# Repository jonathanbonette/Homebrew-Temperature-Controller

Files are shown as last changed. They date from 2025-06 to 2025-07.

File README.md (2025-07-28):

# 🍺 Controlador de Temperatura para Produção de Cerveja Artesanal

Um sistema embarcado moderno e modular para monitoramento e controle térmico durante a brassagem de cerveja artesanal, baseado em perfis de temperatura ajustáveis e lógica de controle robusta.

## Índice

1. [Visão Geral](#visão-geral)  
2. [Objetivos](#objetivos)  
3. [Tecnologias Utilizadas](#tecnologias-utilizadas)  
4. [Arquitetura do Sistema](#arquitetura-do-sistema)  
5. [Modelagem e Lógica de Estados](#modelagem-e-lógica-de-estados)  
6. [Código e Integração Itemis](#código-e-integração-itemis)
7. [Plano de Entregas e Metodologia](#plano-de-entregas-e-metodologia)  
8. [Requisitos do Projeto](#requisitos-do-projeto)  
9.  [Funcionalidades Extras](#funcionalidades-extras)  
10. [Receitas Utilizadas](#receitas-utilizadas)
11. [Resultados e Logs de Processo](#resultados-e-logs-de-processo)
12. [Considerações Finais e Melhorias Futuras](#considerações-finais-e-melhorias-futuras)
13. [Changelog](#changelog)

---

### Visão Geral

Este projeto tem como objetivo desenvolver um controlador inteligente para automatizar o processo de fabricação de cerveja artesanal. O sistema gerencia a temperatura do mosto e ativa automaticamente um mixer, garantindo homogeneidade térmica e aderência a curvas de temperatura personalizáveis.

Com uma arquitetura flexível, o sistema pode ser simulado em ambiente de desenvolvimento e implantado em microcontroladores reais, permitindo testes eficientes e facilidade de manutenção.

### Objetivos

- **Controle térmico preciso:** Manter o mosto dentro da faixa desejada com controle PID e/ou ON/OFF com histerese.
- **Homogeneização eficiente:** Acionar o mixer automaticamente conforme a diferença de temperatura entre sensores.
- **Curvas customizáveis:** Permitir definição e carregamento de receitas personalizadas.
- **Segurança embutida:** Detectar falhas e fornecer alertas visuais/sonoros.
- **Interface acessível:** Oferecer informações em tempo real via display e comunicação serial.
- **Portabilidade e testes:** Simular em PC e transferir facilmente para o ESP32.

---

### Tecnologias Utilizadas

- **Plataforma:** ESP32 (com suporte a FreeRTOS)
- **Linguagem:** C++ com princípios de orientação a objetos
- **Modelagem de Estados:** itemis CREATE / itemis CREATE
- **Interface com Usuário:**
  - Display OLED ou LCD via I2C
  - Teclado matricial 4x4
  - Comunicação UART com PC
- **Sensores:** Temperatura (I2C ou OneWire)
- **Atuadores:** Resistência (PWM), Mixer (GPIO/PWM)
- **Versionamento:** Git + GitHub
- **Documentação:** Doxygen
- **Testes:** Unity ou Google Test *(em definição)*

---

### Arquitetura do Sistema
O controlador é baseado em uma arquitetura modular e desacoplada, onde o microcontrolador ESP32 atua como o núcleo de processamento central, executando tarefas paralelas por meio do FreeRTOS, gerenciando sensores, atuadores e a interface com o usuário.

##### Camada de Sensoriamento
- Sensores de Temperatura: DS18B20 (OneWire) ou simulados via I2C entre dois ESP32 (mestre/escravo)
- Dados são capturados periodicamente por tarefas do sistema operacional (RTOS)

##### Camada de Controle
- Controle ON/OFF com Histerese: simples e seguro, usado como fallback
- Controle PID: integrado via biblioteca PID_v1, ajustando o PWM para regular o aquecimento com precisão
- O controle atua sobre a resistência de aquecimento, com saídas moduladas por PWM

##### Camada de Atuação
- Mixer: acionado via GPIO com lógica baseada na diferença entre sensores (Delta T)
- Resistência: controlada por PWM com duty cycle ajustado pelo controlador
- LEDs: usados para alertas e status de sistema

##### Camada de Interface
- Display OLED: apresenta temperatura atual, setpoint, tempo restante e status do sistema
- Teclado 4x4: entrada de comandos, seleção de receitas, navegação por menus
- UART: comunicação com PC para upload de receitas, logs e visualização remota

##### Camada de Lógica de Estados
- Implementada com itemis CREATE (itemis CREATE), gerando código em C++
- Organiza os fluxos de operação: IDLE, MENU, STANDARD_PROCESS, HEATING, RESTING, FINISHED, etc.
- Transições automáticas com base em eventos

##### Abstração de Hardware (HAL)
- Todos os periféricos (sensores, displays, atuadores) são acessados por meio de camadas de abstração, permitindo simulação em ambiente de PC
- Essa arquitetura permite alta portabilidade e facilita manutenção e testes automatizados

##### Simulação Mestre-Escravo
- Sistema alternativo onde o ESP32 "mestre" controla a brassagem e o ESP32 "escravo" simula a resposta térmica do ambiente
- Utiliza modelo de inércia térmica (RC) para testes realistas do controle PID

---

### Modelagem e Lógica de Estados

Para garantir previsibilidade e segurança no controle da brassagem, a lógica do sistema foi inteiramente modelada por meio de uma máquina de estados finita, utilizando a ferramenta [itemis CREATE](https://www.itemis.com/en/). Essa modelagem define claramente o fluxo de operação do sistema, suas transições, eventos esperados e comportamentos em cada estado.

Abaixo, apresentamos o diagrama completo da máquina de estados desenvolvida para este projeto:

📌 **Estados Principais:** `IDLE`, `MENU`, `STANDARD_PROCESS`, `HEATING`, `RESTING`, `FINISHED`, `EXIT`  ... etc<br>
🔁 **Eventos de Transição:** `start_button`, `tempOk`, `timeout`, `erroSensor`, `abort` ... etc

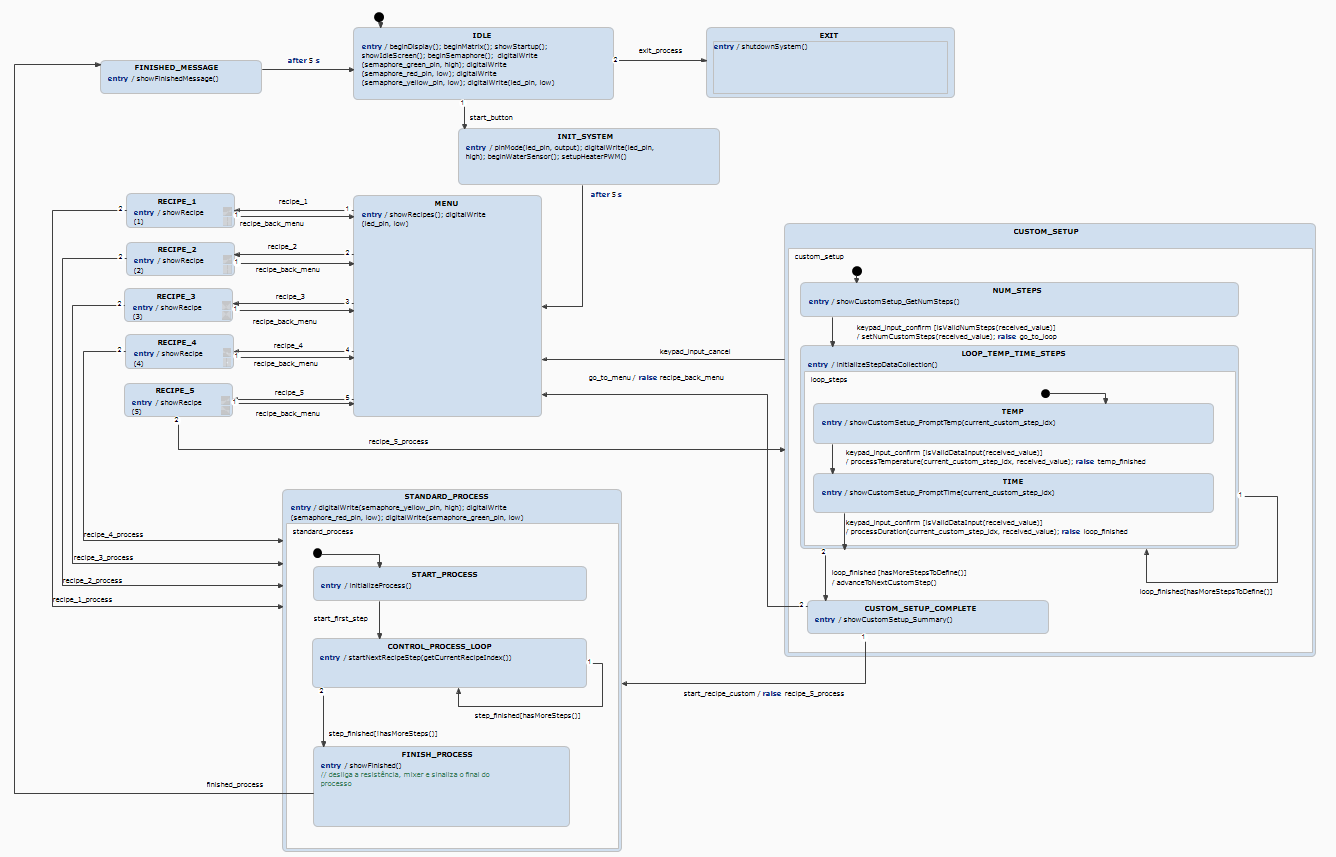
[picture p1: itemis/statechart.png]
Diagrama da Máquina de Estados

*Modelo visual criado com itemis CREATE.*
*Outros arquivos podemser vistos em ```../itemis/project/```*

Essa modelagem permite a geração automática de código C++, que é posteriormente integrado ao projeto embarcado. Isso garante consistência entre o comportamento simulado e a implementação real.

#### Componentes Visíveis na Bancada:
- ESP32 com módulos GPIO expostos
- Display OLED via I2C
- Teclado matricial 4x4
- Sensor de temperatura (DS18B20)
- LED RGB ou semáforo de estado
- Resistência controlada via PWM
- Cabos de alimentação e conexões UART
- ESP32 Mestre-Escravo
- Mixer e Controlador

#### Imagens:

##### Montagem física:
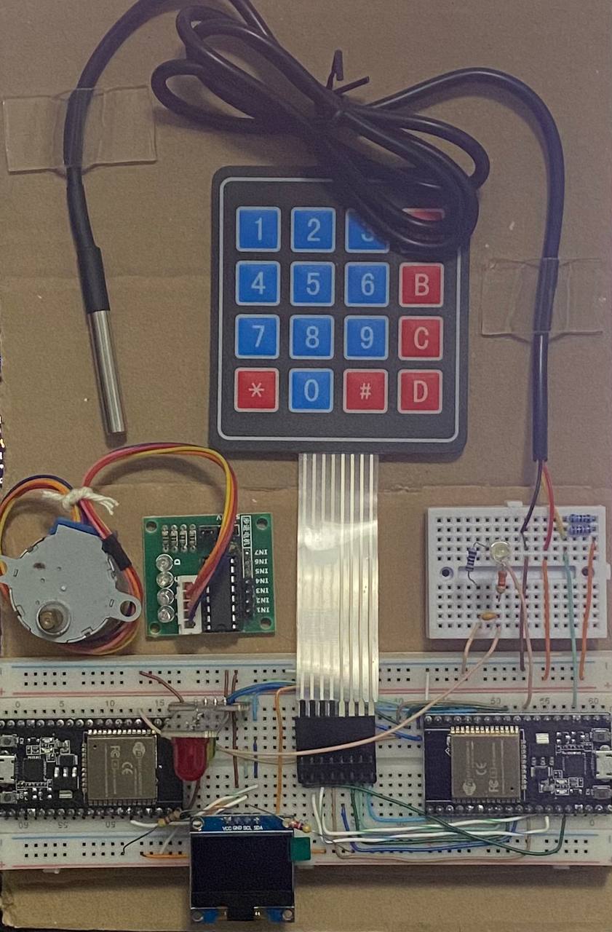
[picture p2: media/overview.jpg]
Montagem Completa

*Vista geral com todos os componentes interligados.*

##### Fritzing:
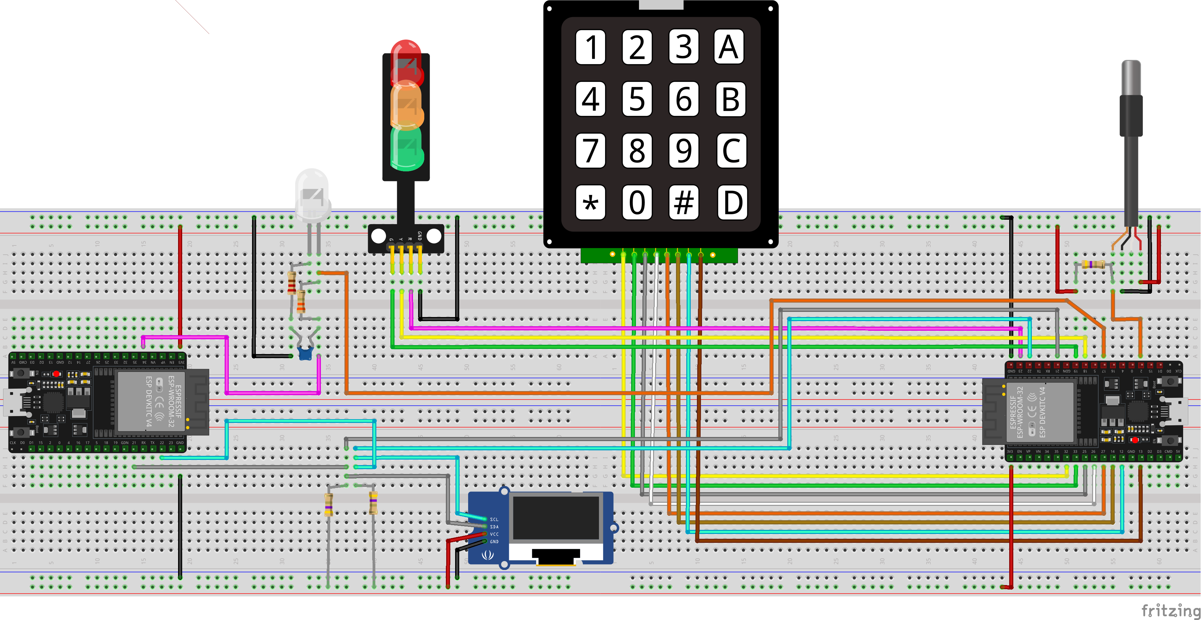
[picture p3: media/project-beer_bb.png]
Fritzing

*Vista geral das ligações dos componentes interligados no Fritzing.*

##### Detalhe do Display:
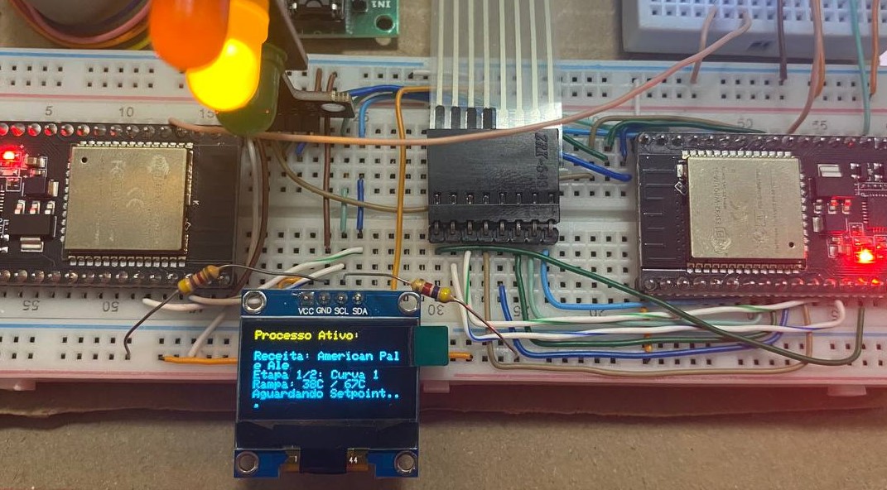
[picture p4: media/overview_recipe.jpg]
Detalhe do Display e Teclado

*Interface de usuário: teclado matricial e display OLED indicando a etapa atual da brassagem.*

#### 🎥 Demonstração em Vídeo:
Abaixo o vídeo demonstra a operação do sistema em tempo real durante uma simulação de brassagem:

[▶️  YouTube](https://youtu.be/FWTbv7r1iv4)

---

### Código e Integração Itemis

A ferramenta itemis CREATE gerou automaticamente os arquivos-fonte para representar a máquina de estados, incluindo:

- `Statechart.h`
- `Statechart.cpp`
- `sc_statemachine.h`, `sc_eventdriven.h`, `sc_timer.h`, `sc_types.h`

Esses arquivos foram integrados ao ambiente de desenvolvimento do ESP32, com callbacks definidos em `StatechartCallback.h` para lidar com as ações de entrada (`entry`) e transições de estados.

* Os arquivos podem ser visualizados em:

```
../freeRTOS/borraco/src/
```

Toda a lógica de resposta ao usuário, atualização de display e leitura do teclado é feita dentro do StatechartCallback, garantindo que o fluxo operacional siga rigorosamente a modelagem definida no itemis CREATE.

* Estrutura de Pastas:

```bash
/src-gen → arquivos gerados
/src     → lógica de aplicação
/include → abstrações de hardware e callbacks
```

Ao modificar a máquina no itemis CREATE e regerar o código, o sistema se adapta automaticamente às novas transições, preservando a lógica central.

---

### Plano de Entregas e Metodologia
O projeto foi estruturado em três fases principais de entrega, cada uma com foco progressivo na consolidação da solução embarcada. Essa divisão visa facilitar o desenvolvimento incremental, permitindo testes contínuos e validação parcial de funcionalidades antes da integração final.

##### Entrega 1 — Fundação e Estrutura Lógica
Objetiva estabelecer a base do projeto, incluindo a modelagem conceitual, estrutura lógica de controle e primeiros testes de fluxo:

- Levantamento e categorização de requisitos funcionais e não funcionais
- Definição da curva padrão de brassagem a ser utilizada
- Modelagem da máquina de estados no itemis CREATE (itemis CREATE)
- Criação do repositório GitHub e organização da base de código inicial

##### Entrega 2 — Desenvolvimento de Funcionalidades-Chave
Foca na implementação dos principais módulos de hardware e controle, promovendo a simulação completa de um processo de brassagem:

- Integração com sensores de temperatura (reais ou simulados via I2C)
- Controle de aquecimento via ON/OFF com histerese e/ou PID
- Visualização de dados em display (OLED/LCD)
- Interface com teclado matricial 4x4
- Comunicação com PC via UART para logs e comandos
- Implementação da lógica de receitas e controle por etapas

##### Entrega 3 — Integração Total e Recursos Avançados
Consolida o sistema com foco em robustez, segurança, testes e usabilidade:

- Adição de funcionalidades extras: alarme sonoro, semáforo LED, logs
- Implementação de detecção de falhas (sensores, comunicação)
- Geração de documentação automatizada via Doxygen
- Testes finais e simulação realista com modelo de inércia térmica
- Apresentação e demonstração funcional completa

---

### Requisitos do Projeto
Os requisitos foram categorizados em Funcionais (o que o sistema deve fazer) e Não Funcionais (como o sistema deve funcionar). O progresso de cada requisito é visualizado através de uma barra de status.

| ID | Tipo | Requisito | Prioridade | Progresso | Entrega Relacionada | Observações |
| :---- | :---- | :---- | :---- | :---- | :---- | :---- |
| **RF01**  | **Funcional** | O sistema deve aplicar algoritmos de controle (PID e/ou ON/OFF com histerese) para manter a temperatura do mosto dentro de uma margem de $\pm 1 ^\circ C$ do *setpoint* definido pela curva de brassagem, acionando as resistências de aquecimento. | Alta | Concluído [🟩🟩🟩🟩🟩] 100% | Entrega 2 | O controle PID foi integrado. A função do controlTask calcula o PID e aplica o Output diretamente ao PWM. |
| **RF02**  | **Funcional** | O sistema deve carregar e executar uma curva de temperatura padrão pré-configurada (ex: 67°C por X min, 78°C por Y min, 100°C por Z min) ao iniciar a brassagem. | Alta | Concluído [🟩🟩🟩🟩🟩] 100% | Entrega 1 | Deixa claro que a curva padrão é a default e como ela é iniciada. (Receitas definidas e lidas, lógica de etapas implementada). |
| **RF03** | **Funcional** | O sistema deve permitir o *upload* de curvas de temperatura customizadas via interface serial (UART), ou via comandos em tela (KEYPAD 4X4). Cada curva deve conter múltiplos *steps* definidos por temperatura e duração, e o sistema deve validar a integridade dos dados recebidos. | Alta | Pendente [🟥🟥🟥🟥🟥] 0% | Entrega 2 | Detalha a forma de *upload* e a necessidade de validação. |
| **RF04**  | **Funcional** | O sistema deve ativar automaticamente o *mixer* quando a diferença de temperatura entre quaisquer dois sensores exceder $1^\circ C$ (Delta T), com um retardo de ativação configurável, para garantir a homogeneização do mosto. | Alta | Concluído [🟩🟩🟩🟩🟩] 100% | Entrega 2 | As novas implementações que foram sugeridas move a lógica para o PID, dessa maneira utiliza a lógica via software e não hardware, desabilitando temporariamente a implementação física do componente do mixer*. |
| **RF05**  | **Funcional** | O sistema deve exibir continuamente no *display* OLED (ou LCD) a temperatura atual do mosto (obtida pelo sensor principal), o *setpoint* da etapa atual da curva, o tempo restante para a etapa atual e o *status* operacional do *mixer* e resistências. | Alta | Concluído  [🟩🟩🟩🟩🟩] 100% | Entrega 2 | A exibição foi aprimorada para indicar claramente a fase de rampa, mostrando "Aguardando Setpoint..." ou o tempo restante, tornando o feedback ao usuário muito mais completo e preciso em relação ao estado real do processo. |
| **RF06**  | **Funcional** | O sistema deve emitir alertas visuais (LEDs) ou sonoros (BUZZER) para notificar o usuário sobre erros críticos de operação (ex: falha de sensor, sobreaquecimento, erro de comunicação), indicando o tipo de falha. | Alta | Concluída [🟩🟩🟩🟩🟩] 100% | Entrega 3 | Especifica os tipos de alerta e a informação a ser passada (tipo de falha). |
| **RF07**  | **Funcional** | O sistema deve permitir ao usuário selecionar o modo de controle (PID ou ON/OFF) antes ou durante o início de uma nova brassagem, através da interface de usuário (teclado ou serial). | Alta | Concluído [🟩🟩🟩🟩🟩] 100% | Entrega 2 | Na implementação 0.8.0 foi implementado o sistema via histerese ON/OFF porém se notou certas inconsistências no desempenho do projeto, no qual não é ideal em uma aplicação real, neste caso foi substituído pela versão 0.9.0 na qua implementa um sistema de PID mais robusto e operacional, desse modo esperamos um comportamento mais esperado do ideal e mais profissional. |
| **RF08**  | **Funcional** | O sistema deve implementar um "Modo de Calibração" para os sensores de temperatura, permitindo ao usuário ajustar *offsets* ou fatores de calibração para leituras mais precisas, com base em temperaturas de referência conhecidas. | Baixa | Concluído [🟩🟩🟩🟩🟩] 100% | Entrega 3 | O sistema permite ajustes porém são hard-coded, sendo possível ajustar antes de fazer o upload do sistema. |
| **RF09**  | **Funcional** | O sistema deve permitir ao usuário visualizar os parâmetros específicos da curva de brassagem em tempo real (ex: *setpoint* de temperatura, duração da etapa) através da comunicação UART, sem interromper o processo atual. | Baixa | Concluído [🟩🟩🟩🟩🟩] 100% | Entrega 2 | O sistema é capaz de fornecer informações ao usuário via UART e via DisplayOLED, detalhando todos os passos e progresso em tempo real. |
| **RF10**  | **Funcional** | O sistema deve registrar em memória não volátil (*Flash* ou EEPROM) os parâmetros de cada brassagem concluída (curva utilizada, temperaturas máximas/mínimas atingidas, duração total) e permitir a consulta desses *logs* via UART. | Média | Concluído [🟩🟩🟩🟩🟩] 100% | Entrega 3 | Funcionalidade adicional de histórico, útil para otimização de receitas. |
| **RF11**  | **Funcional** | O sistema deve suportar a criação de "receitas", que são sequências pré-definidas de curvas de brassagem (ex: *Mash*, *Boil*, *Fermentação*), permitindo ao usuário selecionar e executar uma receita completa. | Alta | Concluído [🟩🟩🟩🟩🟩] 100% | Entrega 3 | A lógica e o gerenciamento das receitas estão integradas no código, sendo possível adicionar quantas receitas fixas quiser com algumas regras de neócio envolvidas como limites de curvas por exemplo. |
| **RF12**  | **Funcional** | O sistema deve fornecer *feedback* visual (ex: ícones no *display* ou LEDs de *status*) sobre o estado atual dos atuadores (resistências ligadas/desligadas, *mixer* ativo/inativo), mesmo quando não houver erro crítico, para facilitar o monitoramento do processo. | Média | Concluído [🟩🟩🟩🟩🟩] 100% | Entrega 2 | Os setups, aquecedores, PWM, i2C, etapas e todos os periféricos existentes foram substituídos por logs no Serial Monitor, os feedbacks visuais são mostrados na barra quando o sistema é iniciado e são gerados a cada step do processo. |
| **RNF01** | **Não Funcional** | A arquitetura de *software* deve ser portável, permitindo que o sistema seja executado tanto em uma plataforma embarcada (ESP32) quanto em um ambiente de simulação no PC, utilizando abstração de *hardware* (HAL) para facilitar a troca de implementações de periféricos. | Alta | Concluído [🟩🟩🟩🟩🟩] 100% | Entrega 3 |  A inclusão da biblioteca PID e a forma como ela se integra (Setpoint, Input, Output) demonstram que o controle é desacoplado da origem da temperatura e do destino do PWM. O simulador I2C aprimorado (com modelo de inércia) mesmo com o uso de uma simulação feita através de um Mestre-Escravo reforça esse requisito. |
| **RNF02** | **Não Funcional** | O código-fonte deve ser implementado em C++ seguindo princípios de Orientação a Objetos (OO), com uso extensivo de polimorfismo e métodos virtuais, para garantir modularidade, reusabilidade e extensibilidade do sistema. | Alta | Em andamento [🟩🟩🟩🟩🟩] 100% | Todas | A adição da biblioteca PID como um objeto e a interação com ela reforçam ainda mais as boas práticas de OO e encapsulamento. |
| **RNF03** | **Não Funcional** | O projeto deve ser versionado no GitHub com um histórico de *commits* claro e descritivo, refletindo o progresso incremental e as mudanças significativas em cada funcionalidade implementada. | Alta | Concluído  [🟩🟩🟩🟩🟩] 100% | Todas | Todosos commits durante o projeto foram feitos periodicamente e com comentários claros e descritivos para enfatizar a qualidade do versionamento. |
| **RNF04** | **Não Funcional** | Toda a base de código deve ser documentada utilizando Doxygen, gerando uma documentação técnica completa das funções, classes, variáveis e módulos, facilitando a compreensão e manutenção por outros desenvolvedores. | Alta | Concluído [🟩🟩🟩🟩🟩] 100% | Entrega 3 | Especifica "toda a base de código" e o benefício da documentação. |
| **RNF05** | **Não Funcional** | O sistema deve incorporar proteção elétrica robusta contra curtos-circuitos, sobreaquecimento e surtos de tensão nos circuitos de controle das resistências e do *mixer*, garantindo a segurança do equipamento e do usuário. | Baixa | Concluído [🟩🟩🟩🟩🟩] 100% | Entrega 3 | A ideaia do projeto era ter algo robusto como circuito com fusíveis, termistores e testes elétricos necessários, porém devido o andaento do projeto não foi necessário a implementação de sistemas como esses pois os dispositivos usados são de baixa voltagem. |
| **RNF07** | **Não Funcional** | Deve ser fornecido um manual de montagem detalhado, com diagramas de fiação, fotos ilustrativas e lista de materiais (BOM), para permitir que um usuário replique o *hardware* do sistema. | Média | Concluído [🟩🟩🟩🟩🟩] 100% | Entrega 3 | Apesar do projeto já ser previamente montado para seu transporte e uso. A montagem foi descrita na documentação, com imagens e demonstrações em vídeo. |
| **RNF08** | **Não Funcional** | O sistema deve gerar *logs* de eventos detalhados (ex: mudanças de *setpoint*, ativação/desativação de atuadores, erros de sensor) via UART, que possam ser facilmente consumidos e analisados por uma aplicação no PC para depuração e monitoramento. | Alta | Concluído [🟩🟩🟩🟩🟩] 100% | Entrega 3 |  Os logs seriais no mestre e escravo são bem descritivos via UART e possuem informações visuais através de LEDS e DisplayOLED.  |
| **RNF09** | **Não Funcional** | O *software* deve ser projetado com alta coesão e baixo acoplamento entre os módulos, utilizando interfaces bem definidas para facilitar futuras expansões e manutenções sem impacto em outras partes do sistema. | Média | Concluído [🟩🟩🟩🟩🟩] 100% | Entrega 2 |  A adição do PID como uma biblioteca separada que interage com Input/Output globais reforça ainda mais o baixo acoplamento e a modularidade. exigida por esse requisito.  |
| **RNF10** | **Não Funcional** | O sistema deve reagir a alterações nos sensores ou comandos de controle e atualizar o estado dos atuadores e do *display* em no máximo 500ms, para garantir uma experiência de usuário responsiva e controle em tempo real. | Baixa | Concluído [🟩🟩🟩🟩🟩] 100% | Entrega 2 | A malha de controle PID é rápida, mas a interface com o usuário poderia passar por um processo melhor de ajustes finos, porém está funcional. |
| **RNF11** | **Não Funcional** | O *software* deve ser submetido a testes unitários automatizados para as camadas de lógica de controle e módulos críticos, utilizando um *framework* de teste (ex: Unity, Google Test) para garantir a robustez e correção do código. | Baixa | Pendente [🟥🟥🟥🟥🟥] 0% | Entrega 3 | Desenvolver testes usando *frameworks* como Unity ou GoogleTest. |
| **RNF12** | **Não Funcional** | O sistema deve permitir o ajuste manual da potência de saída para as resistências (ex: via PWM), permitindo ao usuário sobrescrever temporariamente o controle automático em situações específicas de *fine-tuning* ou emergência. | Baixa | Concluído [🟩🟩🟩🟩🟩] 100% | Entrega 2 | Possui estrutura hard-coded preparada para receber dados facilmente. |
| **RNF13** | **Não Funcional** | O sistema deve detectar e alertar sobre a perda de comunicação com qualquer sensor I²C (ex: por *timeout* ou falha de CRC), e tentar restabelecer a comunicação automaticamente antes de reportar uma falha crítica. | Baixa | Concluído [🟩🟩🟩🟩🟩] 100% | Entrega 3 | A lógica na simulação da temperatura continua a ser a principal detecção de falha de comunicação I2C. Poderia ter retries ou recuperação mais avançada porém é funcional. |
| **RNF14** | **Não Funcional** | O sistema deve ser capaz de calibrar automaticamente ou semi-automaticamente os sensores de temperatura durante o processo de brassagem, compensando variações devido à imersão ou tipo de sensor, utilizando pontos de calibração conhecidos. | Alta | Concluído [🟩🟩🟩🟩🟩] 100% | Entrega 2 | O uso do PID controla e calibra automaticamente a temperatura de brasagem. |
| **RNF15** | **Não Funcional** | A interface de usuário via teclado deve ser intuitiva e eficiente, permitindo a navegação pelos menus e a entrada de dados com um mínimo de passos, para uma boa experiência do usuário. | Média | Concluído [🟩🟩🟩🟩🟩] 100% | Entrega 2 |As informações do processo no display dão clareza para o usuário, com informações claras, tornando a IHM mais eficiente em transmitir o estado do processo. |
| **RNF16** | **Não Funcional** | O consumo de energia do sistema deve ser otimizado para operação de longo prazo, especialmente em modos de espera ou monitoramento, para minimizar o aquecimento desnecessário e potencializar o uso de fontes de energia. | Baixa | Concluído [🟩🟩🟩🟩🟩] 100% | Entrega 2 | Foi implementado sistemas de circuit-breaker do sistema, desligando atuadores e periféricos após uso das receitas, visando o consumo de energia do sistema. |
| **RNF17** | **Não Funcional** | O código deve seguir um guia de estilo de codificação (ex: Google Style Guide, MISRA C/C++) para garantir consistência, legibilidade e manutenibilidade em todo o projeto. | Baixa | Concluído [🟩🟩🟩🟩🟩] 100% | Entrega 3 | Código escrito em formato clean code em C++ e com bastante detalhamento para documentação. |
| **RNF18** | **Não Funcional** | A interface de comunicação serial (UART) deve ser baseada em um protocolo bem definido (ex: ASCII com *checksum* ou JSON para comandos/dados), garantindo a robustez e a interoperabilidade com *softwares* externos (PC). | Alta | Concluído [🟩🟩🟩🟩🟩] 100% | Entrega 2 | A interface de comunicação é feita via displayOLED e teclado matricial. |
| **RNF19** | **Não Funcional** | O sistema deve ter capacidade de *over-the-air (OTA) update* para o *firmware*, permitindo atualizações de *software* remotas sem a necessidade de conexão física via USB, facilitando a manutenção e a adição de novas funcionalidades pós-implantação. | Média | Pendente [🟥🟥🟥🟥🟥] 0% | Entrega 3 | Um requisito de manutenção moderna para sistemas embarcados, crucial para a longevidade do produto. |
| **RNF20** | **Não Funcional** | O *software* deve ser resiliente a falhas temporárias (ex: ruído elétrico, pequenas interrupções de comunicação), implementando mecanismos como *debouncing* para entradas digitais, *timeouts* com *retries* para comunicações e inicialização segura dos periféricos. | Alta | Concluído [🟩🟩🟩🟩🟩] 100% | Entrega 2 | O modelo de inércia térmica no simulador escravo torna a simulação mais realista e robusta, e a controle lida com valores de temperatura (mesmo que simulados) com mais complexidade. Isso reforça a resiliência do sistema de controle em si. |

### Observações:

#### Progresso Geral

- Requisitos Funcionais: **11/12** ✅
- Requisitos Não Funcionais: **18/20** ✅

**Total geral: 29/32 requisitos concluídos** (🔵 ~90%)

---

#### Requisito Funcional - 03: 

* **Descrição:**

*O sistema deve permitir o *upload* de curvas de temperatura customizadas via interface serial (UART), ou via comandos em tela (KEYPAD 4X4). Cada curva deve conter múltiplos *steps* definidos por temperatura e duração, e o sistema deve validar a integridade dos dados recebidos.*

* **Status:**

Durante o desenvolvimento do projeto, um dos requisitos inicialmente propostos precisou ser removido da versão final apresentada. Apesar de sua estrutura conceitual estar devidamente modelada na plataforma Itemis, a implementação prática no código ainda demandava ajustes significativos para garantir um funcionamento estável e conforme os padrões de qualidade exigidos.

Em função do tempo disponível para entrega e da complexidade envolvida na correção de determinados bugs, optou-se por desativar temporariamente essa funcionalidade. Essa decisão foi tomada com o intuito de priorizar a entrega de um sistema funcional, estável e coerente com os demais requisitos implementados, evitando que possíveis inconsistências técnicas impactassem negativamente na experiência de uso ou na avaliação do projeto.

A funcionalidade removida permanece documentada e estruturada de forma modular, o que possibilita sua futura reintegração ao sistema com as devidas correções e validações. Essa abordagem evidencia a preocupação com a qualidade do código e com a viabilidade técnica do projeto, demonstrando uma postura responsável diante das limitações de tempo e recursos enfrentadas na reta final do desenvolvimento.

* **Planejamento Futuro:**

Esta funcionalidade permanece documentada e com estrutura modular, permitindo que seja reintegrada em futuras versões do sistema com as devidas correções e validações.

#### Requisito Não Funcional - 11:

* **Descrição:**

O *software* deve ser submetido a testes unitários automatizados para as camadas de lógica de controle e módulos críticos, utilizando um *framework* de teste (ex: Unity, Google Test) para garantir a robustez e correção do código.

* **Status:**

Durante a fase final de desenvolvimento, foi priorizado a estabilização das funcionalidades principais e a integração dos módulos em tempo real, o que exigiu esforços intensivos de depuração e testes manuais. Com isso, a implementação de testes unitários automatizados, embora considerada uma boa prática de engenharia de software, acabou sendo adiada devido à limitação de tempo e à necessidade de ajustes constantes no código base.

Além disso, a configuração adequada do ambiente de testes com frameworks como Unity ou Google Test requer um tempo inicial de estruturação e integração que não pôde ser absorvido sem comprometer o cronograma das demais entregas.

* **Planejamento Futuro:**

A inclusão de testes automatizados continua sendo uma etapa planejada para versões futuras do projeto porém segue com **prioridade baixa**. Com a estabilização da base de código, será possível estruturar um ambiente de testes e implementar uma suíte de testes unitários abrangente, aumentando a confiabilidade e facilitando futuras manutenções.

#### Requisito Não Funcional - 19:

* **Descrição:**

O sistema deve ter capacidade de *over-the-air (OTA) update* para o *firmware*, permitindo atualizações de *software* remotas sem a necessidade de conexão física via USB, facilitando a manutenção e a adição de novas funcionalidades pós-implantação.

* **Status:**

A implementação do mecanismo de atualização OTA exige uma arquitetura de firmware mais robusta, com particionamento de memória apropriado (dual bank ou bootloader dedicado), além de um gerenciamento seguro de pacotes de atualização e verificação de integridade. Durante a fase de desenvolvimento, constatou-se que a plataforma de hardware utilizada apresentava limitações de memória e conectividade que comprometeriam a implementação segura e confiável desse recurso.

Além disso, o desenvolvimento de um sistema OTA funcional implicaria em um aumento considerável na complexidade do projeto, demandando integração com protocolos de rede, criptografia e fallback seguro em caso de falha durante a atualização — etapas que exigiriam tempo e testes adicionais fora do escopo da entrega atual.

Diante dessas limitações técnicas e do foco na entrega de um sistema funcional e testável localmente, optou-se por adiar esse requisito para versões futuras.

* **Planejamento Futuro:**

Para o projeto viu-se com o andamento que a funcionalidade de OTA foi completamente descartada para versões futuras do sistema, especialmente em contextos de implantação real.

---

### Funcionalidades Extras
Nesta etapa do projeto, foram incorporadas funcionalidades adicionais que, embora não estejam entre os requisitos principais, enriquecem a usabilidade e o controle do sistema.

##### Teclado Matricial 4x4:
Permite ao usuário navegar por menus, selecionar receitas, iniciar ou abortar processos e ajustar configurações diretamente no sistema, sem necessidade de interface externa. A interação torna o sistema autônomo e mais acessível.

##### Semáforo Indicador (RYG):
Módulo visual com LEDs nas cores vermelho, amarelo e verde que indicam, de forma intuitiva, o estado atual da brassagem:

🔴 **Vermelho:** Erros ou saída do sistema.<br>
🟡 **Amarelo:** Aquecimento ou rampa de temperatura.<br>
🟢 **Verde:** Pronto para inicializar as receitas.

##### Visualização Gráfica da Curva de Temperatura:
Possibilidade futura de integrar o sistema com uma interface gráfica no PC, permitindo ao usuário visualizar em tempo real o progresso da curva de temperatura e eventos do processo.

##### Registro e Exportação de Logs:
Registro das sessões de brassagem em memória e envio via UART, permitindo análise posterior do desempenho térmico e histórico das receitas utilizadas

---

### Receitas Utilizadas
Aqui é relacionado as receitas que foram escolhidas para serem implementadas no projeto, desde básicas até mais elaboradas.
| Receita | Etapa| Temperatura (°C) | Tempo (min) | Observações| Referência |
|:----:|:----:|:----:|:----:|:----:|:----:|
| **American Pale Ale** | Mostura (Infusão) | 67 | 60 | Conversão de amido em açúcares fermentáveis via enzimas | thebeerjunkies.com/pale-ale/ |
| | Mash Out (Aquecimento Final) | 76 | 10 | Inativação enzimática, reduz viscosidade e facilita a lavagem dos grãos | |
| **Witbier** | Descanso de Proteína | 50 | 15 | Quebra de proteínas grandes, melhora corpo, espuma e clareamento | ultralowbrewing.com/wp-content/uploads/2022/01/guide-to-step-mashing.pdf |
| | Descanso de Sacarificação | 68 | 60 | Conversão de amido em açúcares fermentáveis e não fermentáveis, ajusta final da cerveja | |
| | Mash Out | 76 | 10 | Inativação enzimática e preparo para lavagem | |
| **Belgian Dubbel** | Descanso de Proteína | 52 | 15 | Quebra de proteínas para corpo, estabilidade de espuma e nutrientes de levedura | byo.com/article/belgian-dubbel/ | |
| | Sacarificação Baixa | 64 | 45 | Gera mais maltose fermentável para um final seco | |
| | Sacarificação Alta | 72 | 15 | Produz dextrinas para corpo e dulçor | |
| | Mash Out | 76 | 10 | Encerra a mostura e inativa enzimas | |
| **Bohemian Pilsen** | Descanso de Acidez/Ferúlico | 45 | 15 | Ajusta pH, ajuda a criar notas de cravo (em trigo) e melhora a sensação da boca | forum.northernbrewer.com/t/converting-a-step-mash-recipe-into-a-single-infusion-mash/4630 |
| | Descanso de Proteína | 52 | 15 | Melhora claridade e estabilidade da espuma | |
| | Beta-Amilase | 63 | 45 | Máxima produção de maltose, final seco | |
| | Alpha-Amilase | 72 | 15 | Produção de dextrinas, aumenta corpo e sensação de boca | |
| | Mash Out | 76 | 10 | Inativação enzimática e preparação para lavagem | |
| **Customizada** | N | N | N | N | A receita customizada deverá ser informada pelo usuário na tela de receitas, ele pode criar as etapas conforme preferência |

---

### Resultados e Logs de Processo
Durante a execução de uma receita, o sistema registra uma série de eventos via UART, que incluem:

- Aquisições de temperatura
- Atingimento de setpoint
- Ativação/desativação dos atuadores
- Tempo restante de cada etapa
- Alertas ou falhas detectadas

Incluindo o registro em segundos da temperatura durante as etapas de brasagem, nas quais no final de cada processo podemos obter com o botão ```*``` na etapa ```IDLE``` os logs entre ```Tempo X Temperatura``` e assim usar para construir um gráfico.

Como um exemplo prático podemos pegar o *output* da **Receita: APA**.

- Durante a etapa de brasagem da Receita 1 foi gerado esses valores para as Curvas 1 e 2.
```d
TempoSeg;TempAtual;SaidaPWM;Curva
11;25.11;1023;1
12;25.10;1023;1
...
...
...
179;77.21;548;2
180;77.18;543;2
182;77.13;539;2
```
*Os tempos de cada curva foram reduzidos para 1 minuto para fins de testes*

Usado o script que se encontra em ```../freeRTOS/borracho/log_analysis/log_analysis.py```

Podemos gerar o gráfico e ver como o controle PID atua em relação a oscilação e comose comporta na estabilização durante a Curva 1 e a Curva 2.

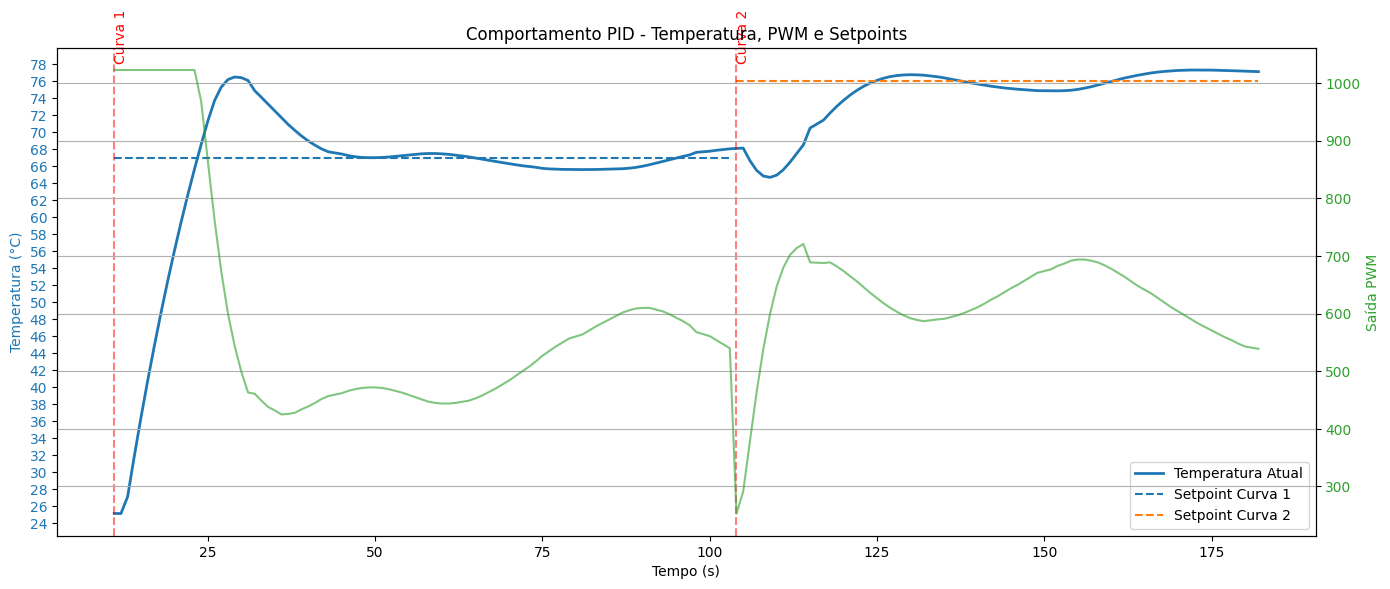
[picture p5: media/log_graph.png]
Gráfico do Controle PID


Além disso podemos obter alguns dados essenciais, como:

```text
* Métricas da Curva 1 (Setpoint = 67°C):
Overshoot: 9.50 °C
Tempo de subida: 13.00 s
Tempo de estabilização: 43.00 s
Erro médio absoluto: 4.85 °C

* Métricas da Curva 2 (Setpoint = 76°C):
Overshoot: 1.32 °C
Tempo de subida: 21.00 s
Tempo de estabilização: 123.00 s
Erro médio absoluto: 2.30 °C
```

Vendo essas saídas,podemos ver que o projeto trabalha como proposto e a uma margem bem aceitável de aplicações mais profissionais.

---

### Considerações Finais e Melhorias Futuras

O projeto apresentado demonstrou a viabilidade de construir um sistema embarcado robusto para controle de temperatura no processo de brassagem artesanal, com foco em modularidade, usabilidade e precisão.

Entre os pontos fortes destacam-se:

- Integração funcional entre modelagem e implementação (itemis CREATE → C++)
- Controle PID com desempenho comprovado em testes reais e simulados
- Interface intuitiva com teclado e display
- Arquitetura escalável e bem documentada

**Melhorias Futuras Planejadas:**

- Reativar o sistema de upload de curvas customizadas via UART
- Implementar testes automatizados com Google Test
- Explorar atualização OTA com particionamento de firmware
- Adicionar interface gráfica para acompanhamento via PC
- Estender o projeto para controle de fermentação e dry-hopping

Esse projeto abre caminho para futuras automações no universo da produção artesanal de cerveja, com base em princípios sólidos de engenharia embarcada.

---

### Changelog

Este *changelog* registra as principais versões e funcionalidades implementadas no projeto.

* **v0.1.0** - **Início do Projeto**
    * Configuração inicial do ambiente de desenvolvimento.
    * Criação do repositório, requisitos e documentação básica.

* **v0.2.0** - **Validação de Hardware Básico**
    * Implementação de uma prova de conceito de "blink" com ESP32 e LED.

* **v0.3.0** - **Fundação do Software**
    * Estrutura de software com FreeRTOS e tarefas.
    * Integração inicial com máquina de estados (itemis CREATE) e comunicação serial.

* **v0.4.0** - **Interface Visual (OLED)**
    * Adição do driver e interface do display OLED (I2C).
    * Visualização de estados e mensagens no display.

* **v0.5.0** - **Interface de Entrada (Teclado)**
    * Integração do driver para teclado matricial 4x4.
    * Funcionalidade de navegação nos menus principais (`IDLE`, `MENU`).

* **v0.6.0** - **Simulação de Processo**
    * Estrutura de dados para receitas e etapas em memória.
    * Implementação da lógica de gerenciamento de etapas com simulação de temperatura e tempo.
    * Navegação completa para seleção e início de receitas pré-definidas.
    * Integração e controle do Módulo Semáforo LED.

* **v0.7.0** - **Primeira Medição de Hardware**
    * Integração de sensores de temperatura DS18B20 via One-Wire para leituras reais.
    * Substituição da simulação de temperatura por dados reais na lógica de controle e display.
    * Aprimoramento do display com temperatura real e *countdown* formatado.
    * Implementação inicial de detecção de falha de sensor.

* **v0.8.0** - **Controle Básico e Ambiente de Testes**
    * Migração para um simulador de temperatura I2C (mestre-escravo ESP32) para testes mais robustos.
    * Implementação de controle ON/OFF com histerese usando PWM real.
    * Configuração do ESP32 escravo com filtro RC para simular inércia térmica.
    * Detecção aprimorada de falhas de comunicação I2C.

* **v0.9.0** - **Controle Avançado de Temperatura**
    * Substituição do controle ON/OFF por um **controlador PID** utilizando a biblioteca `PID_v1`.
    * Gerenciamento de tempo de etapa condicional (contagem regressiva só inicia após o *setpoint* ser atingido).
    * Refinamento do modelo de inércia térmica no simulador escravo para validar o desempenho do PID.
    * Melhoria na desativação segura do aquecedor ao finalizar ou abortar o processo.
* **v1.0.0** - **Lançamento Oficial**
    * **Sistema Funcional Completo:** Todas as funcionalidades de controle (PID), interface de usuário (teclado, display, semáforo) e gerenciamento de receitas estão implementadas, testadas e operacionais.
    * **Integração de Atuadores:** Implementação e controle do mixer com lógica de ativação por Delta T.
    * **Robustez e Segurança:** Mecanismos de detecção de falhas e alertas visuais/sonoros estão integrados.
    * **Documentação Completa:** Documentação do código (Doxygen), manual de montagem e guia do usuário estão finalizados.
* **v1.1.0** - **Adição de Funcionalidade de Logging**
    * Implementação da **geração de logs de eventos em formato CSV**.
    * Os logs registram parâmetros de cada brassagem concluída, incluindo a curva utilizada, temperaturas e duração total.
    * Os dados podem ser consultados via comunicação serial (UART) para análise posterior.

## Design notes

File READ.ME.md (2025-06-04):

# Controlador de Temperatura para Produção de Cerveja Artesanal

Este projeto tem como objetivo o desenvolvimento de um sistema embarcado para auxiliar no processo de fabricação de cerveja artesanal, controlando a temperatura e o mixer (agitação) do mosto, com base em curvas programáveis de temperatura vs tempo.

## Objetivos

- Controlar a temperatura em tempo real utilizando controle PID ou ON/OFF com histerese.
- Ativar o mixer com base em condições específicas.
- Permitir a simulação da lógica no PC, sem hardware físico.
- Garantir segurança com detecção de falhas nos sensores.
- Prover interface com o usuário via PC e LCD.

---

## Tecnologias e Ferramentas

- ESP32
- C/C++
- Yakindu / itemis CREATE (opcional para máquina de estados)
- LCD 4x16
- Sensor de Temperatura (I2C)
- Comunicação UART com o PC
- Doxygen (documentação)
- Git/GitHub (versionamento)

---

## Arquitetura do Sistema

```plaintext
Sensor de Temperatura (I2C)
        ↓
Microcontrolador (PID + UI)
├── LCD 4x16
├── Resistência (GPIO/PWM)
├── Mixer (GPIO/PWM)
├── Botões
└── ESP32 UART ⇄ PC (Interface)
```

---

## Requisitos Funcionais

- Curva de temperatura padrão (ex: 67°C → 78°C → 100°C).
- Inserção de novas curvas via UART.
- Controle PID ou ON/OFF com histerese.
- Mixer é ativado quando a diferença entre dois sensores ≥ 1°C.
- Alerta e desativação em caso de falha no sensor.
- Máquina de estados via Yakindu ou C++ orientado a objetos.
- Simulação possível em ambiente de PC.

---

### Entregas

##### Entrega 1:
- Levantamento de requisitos
- Diagrama do sistema
- Curva padrão
- Modelagem da máquina de estados

##### Entrega 2:
- Drivers de sensores/atuadores
- Controle PID/ON-OFF funcional
- Comunicação com PC via UART

##### Entrega 3:
- Integração total
- Funcionalidade extra (ex: alarme, logs)
- Detecção de falhas
- Documentação (Doxygen)
- Demonstração

---

### Funcionalidade Extra (a definir)
##### Exemplos possíveis:
- Alarme sonoro
- Visualização gráfica da curva
- Modo de calibração
- Registro de logs

---

### Organização do Projeto
```plaintext
src/
├── main.cpp
├── controller/
│   ├── pid_controller.cpp
│   └── onoff_controller.cpp
├── drivers/
│   ├── sensor_temp.cpp
│   ├── heater.cpp
│   └── mixer.cpp
└── interface/
    ├── pc_uart.cpp
    └── lcd.cpp

docs/
└── README.md

yakindu/
└── statechart.sct (se aplicável)

Doxyfile (para geração da documentação)
```

---

### Ideias iniciais:
```plaintext
[Inicialização]
      ↓
    Idle ────────┐
      ↓          │
  Aquecendo      │
      ↓          │
Estabilizando    │
      ↓          │
 MixerLigado     │
      ↓          │
PróximoDegrau    |
      ↓          │
 Finalizado      │
      ↓          │
    (FIM) ◄──────┘
```

### Eventos e transições
| Evento | Transição |
| :---: | :---: |
| start | Idle → Aquecendo |
| tempOk | Aquecendo → Estabilizando |
| deltaT > 1°C | Estabilizando → MixerLigado |
| degrauCompleto | MixerLigado → PróximoDegrau |
| fimDaCurva | PróximoDegrau → Finalizado |
| erroSensor / falha | Qualquer estado → Erro |

### Changelog

- release/1.0.0: criar repositório com requisitos e o README
- release/2.0.0: código funcional de um blink com ESP32 e LED
- release/2.1.0: ajuste dos estados e códigos para simulação inicial com ESP32 e interação com estados e UART

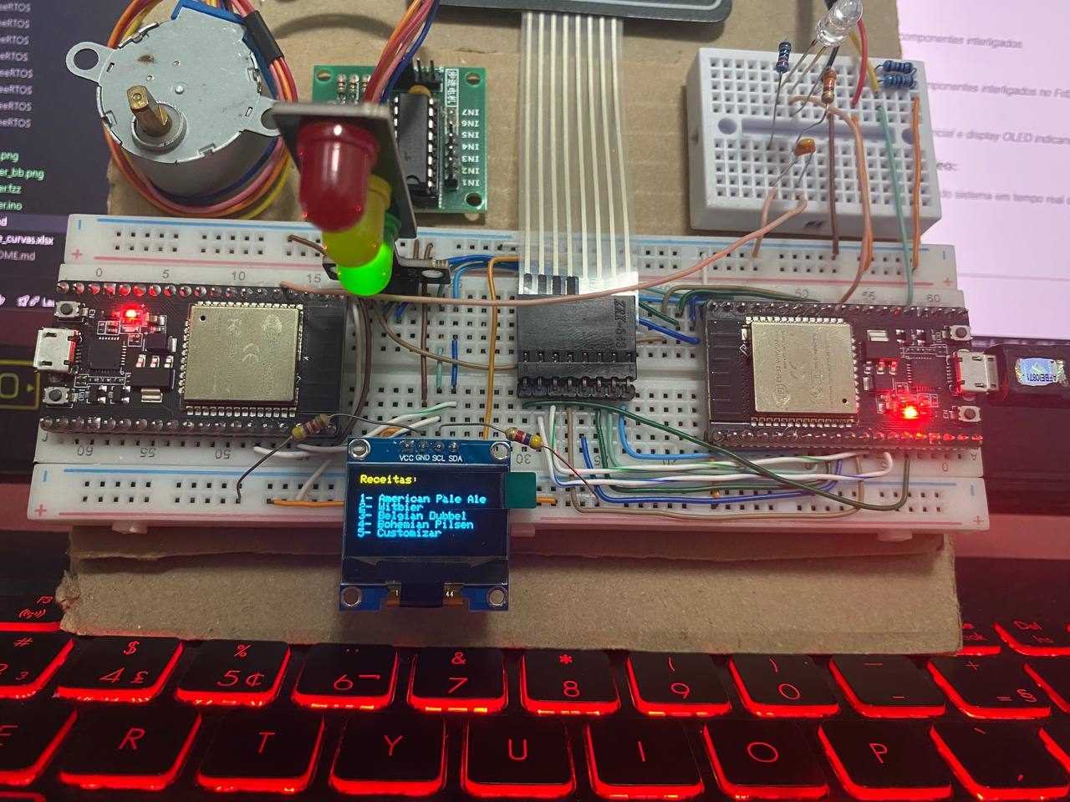
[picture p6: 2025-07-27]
media/overview_menu.jpg

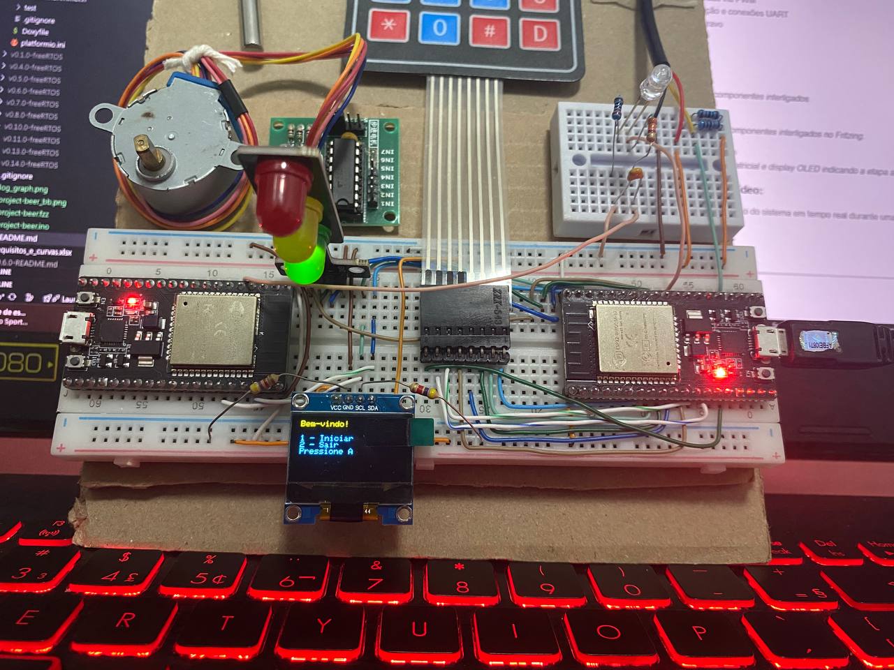
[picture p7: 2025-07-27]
media/overview_idle.jpg

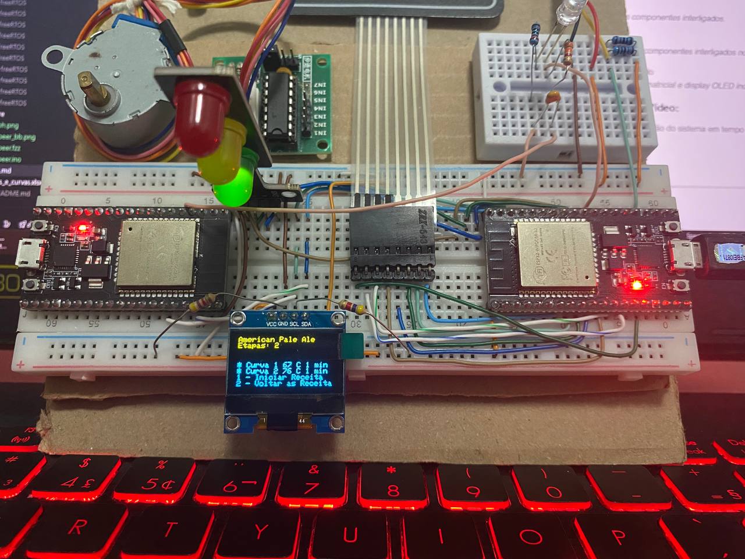
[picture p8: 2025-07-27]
media/overview_recipe_sel.jpg

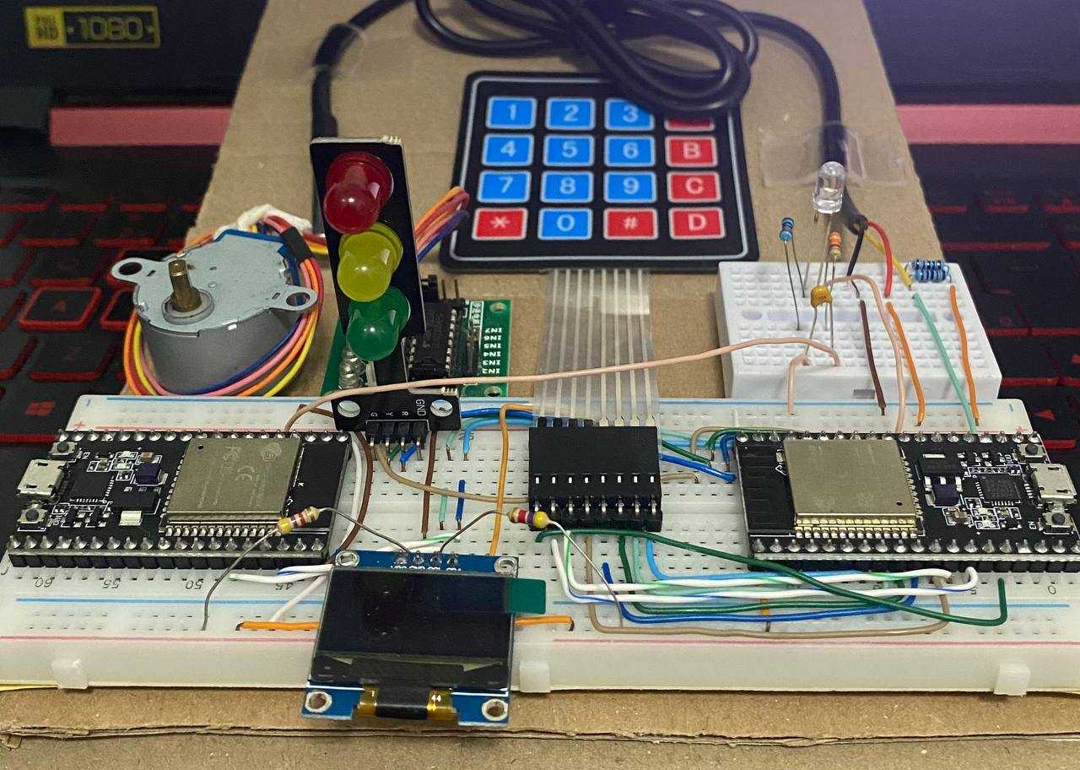
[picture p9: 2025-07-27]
media/overview_front.jpg

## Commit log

2025-06-04 feature: add readme and reqs to project
    [requisitos_e_curvas.xlsx]
2025-06-04 release/2.1.0 : creating uart and esp32 communication with uart and display
2025-06-16 atualizando requisitos funcionais e nao funcionais e atualizando a estrutura do README
    [requisitos_e_curvas.xlsx]
2025-06-22 feature: standard process structure with mock and temperature and semaphore rgb
2025-06-26 feature: implement ds sensor and interface with time and temerature
2025-07-23 feature: add master/slave for communication with pwm and i2c and control with systeresis
2025-07-23 feature: change hysteresis to pid system for temperature simulation
2025-07-26 feature: add doxygen file and docs to project final stage
2025-07-27 readme.md finishing documentation
    [project-beer.fzz, requisitos_e_curvas.xlsx]
